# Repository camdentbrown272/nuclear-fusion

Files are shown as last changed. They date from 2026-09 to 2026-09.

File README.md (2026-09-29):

# nuclear-fusion — Cold-Fusion Geometry Optimisation

This repository documents a design effort to find the geometric configuration of a **cold** (condensed-matter, room-temperature-class) nuclear experiment with the best chance of producing a **measurable, credible** signal. All reasoning is written down so others can audit it.

## Start here
1. [`docs/00-charter.md`](docs/00-charter.md): mission, scope, honest prior, the two hypotheses.
2. [`docs/01-master-plan.md`](docs/01-master-plan.md): phases, candidate configurations, evaluation matrix.
3. [`docs/models/M0-rate-budget.md`](docs/models/M0-rate-budget.md): first-principles numbers that set the design objective.

## Layout
| Path | Contents |
|---|---|
| `docs/research/` | Literature digests R1–R7 with evidence grades |
| `docs/models/` | Quantitative models M0–M6 (briefs in `docs/models/briefs/`) |
| `docs/decisions/` | Architecture/decision records (ADR) |
| `docs/design/` | Iteration designs and red-team reviews |
| `sim/` | Model code (`python3 sim/<file>.py`; needs numpy, scipy, matplotlib) |

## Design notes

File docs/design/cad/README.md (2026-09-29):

# 3D model — iteration 1 rev C

Generated by `sim/cad_dfm.py` (CadQuery; `pip install cadquery`). Every dimension comes from
`docs/design/iteration-1.md`; change a parameter at the top of the script and rerun to regenerate.

| File | Use |
|---|---|
| `dfm_cell.step` | Single DFM cell, editable CAD (Fusion 360, FreeCAD, SolidWorks, Onshape). True 12 µm membrane, full hex catch grid |
| `dfm_cell.stl` | Same cell as one mesh, for quick viewing or 3D printing (in mm) |
| `dfm_cell.glb`, `dfm_house.glb`, `gamma_station.glb` | Coloured meshes for any glTF viewer (Windows 3D Viewer, Blender, gltf-viewer.donmccurdy.com) |
| `dfm_house.step` | 8-position array in its Cu / ³He / borated-HDPE house (simplified cells) |
| `gamma_station.step` | NaI well calorimeter with the mini permeation cell in its Pb / borated-HDPE / veto shield (ADR-006) |
| `*.gltf.json` | Same meshes as self-contained glTF JSON, used by the web viewer |
| `viewer.html` | Interactive viewer (section cut, part descriptions) |

Run the viewer locally with `cd docs/design/cad && python3 -m http.server`, then open
<http://localhost:8000/viewer.html>. It loads three.js from a CDN.

The layers that are thinner than 0.1 mm are drawn at true thickness, except the Au exit finish
(50 nm, drawn 20 µm). The viewer can thicken the membrane, Au finish and ΔE detector ×40.

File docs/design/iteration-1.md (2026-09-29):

# Iteration 1 (rev C) — Detector-Facing Membrane Array "DFM-8" and claim arms

**Status:** revision C, after all four red-team-1 reviews and M7:
- [ADR-005](../decisions/ADR-005-iteration1-revB.md): physics, statistics and claim fidelity;
- [ADR-006](../decisions/ADR-006-gamma-station-modulation.md): γ station and modulation;
- [ADR-007](../decisions/ADR-007-engineering-revC.md): engineering and safety.
**Date:** 2026-09-29
**Frozen analysis plan:** [preregistration-v1.md](preregistration-v1.md)
**Earlier version:** rev A (git `77887a6`) used quadrant skins on one membrane. The reviews showed that geometry cannot hold the claimed regimes (ADR-005 §1).
**Lead designer:** Claude. Every parameter cites its source in §14.

---

## 0. The configuration in one paragraph

- **The membrane.** A **12 µm annealed palladium membrane, 20 mm active diameter**, forms the wall between two chambers.
  - It is press-bonded to a corrugated **platinum** annulus. Platinum does not absorb hydrogen, so the membrane can swell freely while an all-metal seal holds it.
  - Both chambers hold D₂ at 0.5 bar, so the membrane carries no significant pressure load. A 0.3 mm molybdenum grid and a relief valve protect it if that balance is lost.
  - Deuterium that crosses the membrane is **pumped back into the cell** through a closed, helium-tight loop. This keeps the sealed cell's gas and heavy water in balance (ADR-007).
- **The entry face (top)** is the cathode of a small **sealed, all-metal, PTFE-lined electrolytic cell**: 1.0 M LiOD in low-tritium D₂O, with a Pt mesh anode 4 mm above. The cell loads the membrane to D/Pd ≥ 0.9.
- **The exit face (bottom)** gets **one of three finishes per membrane**. Each finish sets the loading state of the *whole* foil:
  - **H-L:** 50 nm Au cap. High loading, no through-flux. It behaves like SRI's closed cathode, with deuterium movement driven by current steps.
  - **H-M:** 20 nm Ni. High loading with a small through-flux.
  - **FX:** half bare Pd, half Pd/CaO multilayer. Maximal flux at moderate loading.
- **Charged-particle detection.** A **quadrant silicon ΔE–E telescope** sits 4 mm below the exit face. Because the foil is thinner than the range of a 3 MeV proton, the telescope sees fusion protons from **anywhere in the foil**, including the electrolyte-facing surface. The proton energy tells roughly how deep they were born.
- **Helium-4.** Every cell accumulates ⁴He statically in two sealed, polymer-free volumes: the ~30 cm³ front and the headspace. Post-run melts recover retained helium.
- **The array.** **Eight such membranes from two screened Pd lots** run in two stages of four. Each stage shares a low-background house with four controls:
  - a Pt-membrane D₂O twin;
  - two light-water twins;
  - a blank telescope.
  - The house also contains a ³He neutron bank and a muon veto. The 511 keV / e⁺e⁻ channel runs in a separate lead-shielded **γ station** (ADR-006).
- **Parallel Tier-1 arms.** Two further arms run alongside and test the best-graded claims at their original conditions:
  - Iwamura-type gas-permeation transmutation cells (**C3-G**, Cs→Pr);
  - four SRI-type closed wire cathodes (**C1**).

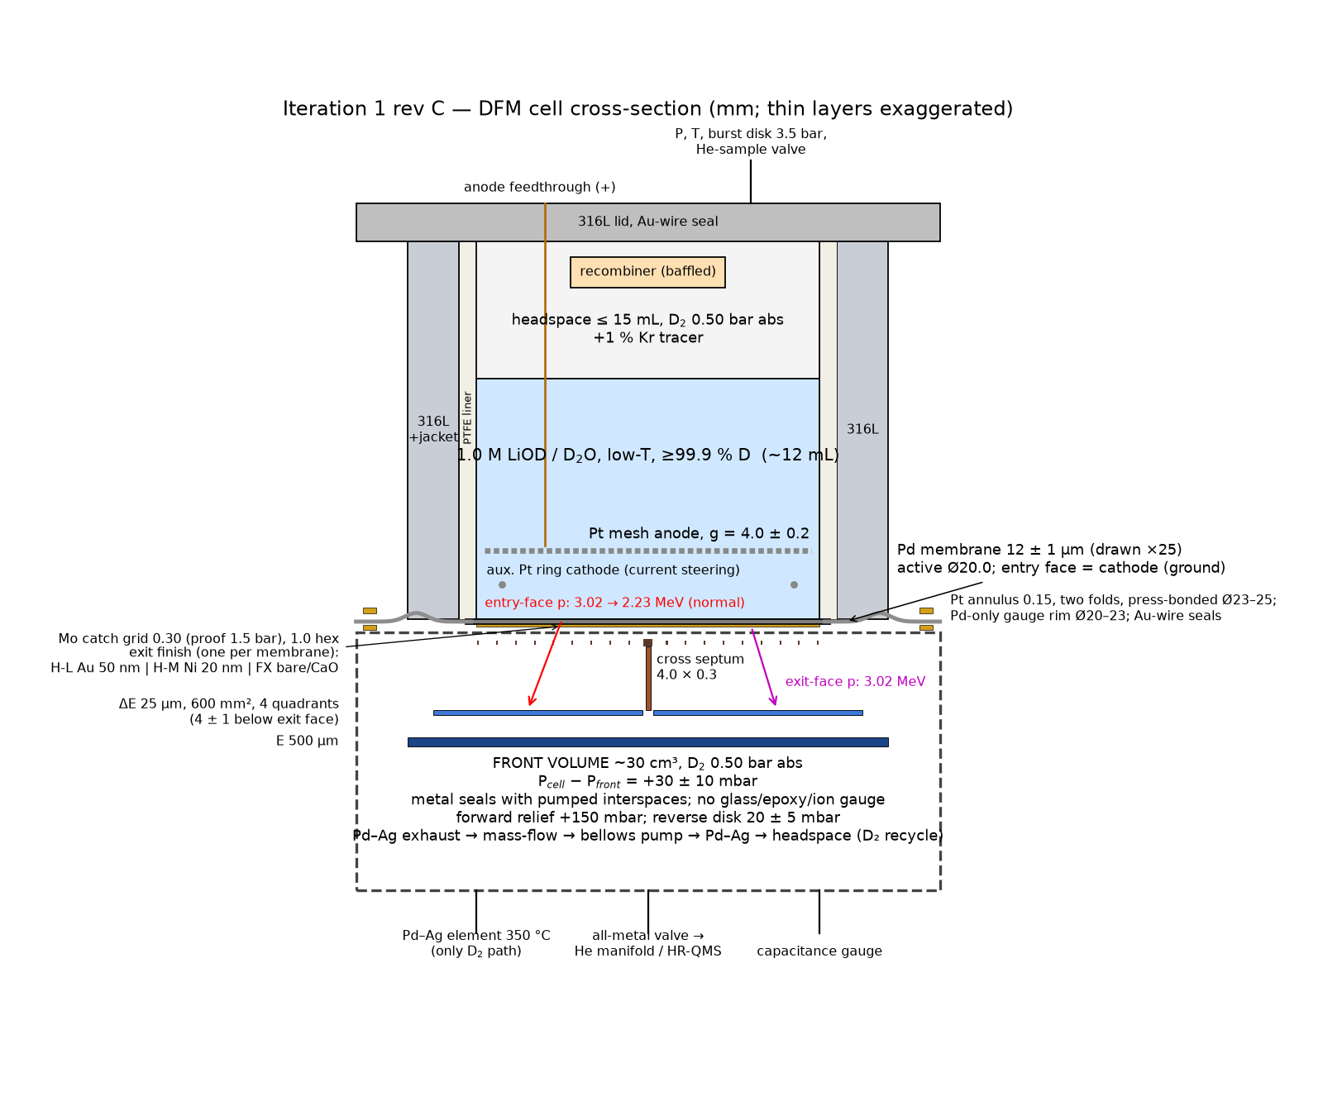
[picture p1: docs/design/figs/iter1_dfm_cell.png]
DFM cell cross-section


**3D model:** STEP/STL/glTF files and an interactive viewer are in [`cad/`](cad/README.md) (generated by `sim/cad_dfm.py`).

## 1. Objective and honest odds

- **Objective (ADR-003).** Reproduce the claimed conditions at a detector-visible location, in enough independent samples, with detectors reaching ≲ 1 % of each claimed magnitude, and with controls that make a detection credible.
- **Physics prior (M0).** The gap to a detectable rate under standard physics is 89–115 e-folds. Static screening gives about 9–13 eV at every lattice site (M1).
- **P(claim-rule positive).** P(any claim-rule positive that survives controls) ≲ 3 %.
- **What a null buys.** An all-null outcome sets **magnitude limits conditional on reaching the claimed regime**, per claim, normalised per area and per volume. Its Bayes factor against existence is only ~1.4–1.6 (red-team-1C S-7). It is *not* a refutation, and the write-up will say so (pre-registration §5).

## 2. Programme architecture

| Tier | Arm | What it tests | ADR-003 score (1D §4, revised) |
|---|---|---|---|
| **1** | **DFM-8** (§3–§6) | H1a (charged particles at every depth), H2 (⁴He, the most sensitive accounting), SRI loading at a visible location, flux regime, desorption | ≈ 0.53 for SRI plus Lipson/NTT terms; the only arm that makes H1 nulls informative |
| **1** | **γ station** (§4.3, ADR-006) | H1c: Czerski e⁺e⁻ channel. 8″×8″ NaI well around a mini permeation cell, D₂O/H₂O factorial | ≈ 0.14–0.2; MDA 5×10⁻³ pairs s⁻¹ at sea level, 3×10⁻⁴ at ≥ 30 m w.e. |
| **1** | **C3-G ×5** (§7.1) | Iwamura permeation transmutation, primary Cs→Pr | ≈ 1.1 |
| **1** | **C1 ×4 + H₂O twin** (§7.2) | SRI/ENEA heat + ⁴He in closed wire cathodes | ≈ 0.7 |
| 2 | Nanocomposite / Ni–Cu furnace (§8.2) | Kitamura / Clean Planet | promoted when claimant-lineage material is secured |
| 3 | Co-deposition on a PSD scintillator (§8.1) | SPAWAR chemistry | low credibility, cheap |

## 3. The DFM cell

### 3.1 Cross-section

Dimensions in mm unless noted; not to scale.

```
                 anode feedthrough (alumina-brazed, +)      P, T, burst disk (3.5 bar), He-sample valve
                          |                                        |
        +=================|========================================|=============+  316L lid, Au-wire seal
        |  headspace <=15 mL, D2 0.50 bar abs (+1 % Kr); make-up/recycle inlet  |
        |  recombiner (hydrophobic Pt/Al2O3, >=20 above liquid, baffle, arrestor) |
        |  +-- 316L body (water jacket), PTFE liner 1.0 spring-loaded, bore 20 -+ |
        |  |  1.0 M LiOD / D2O (low-T, >=99.9 % D), ~12 mL                        | |
        |  |  ======== Pt mesh anode (>=50 % open, pitch <=1) ========  g = 4.0   | |
        |  |  o aux. Pt ring cathode (current steering, ADR-006)   RTD thermowell | |
        |  |  ~~~~~~~~ ENTRY FACE = cathode (ground), etched annealed Pd ~~~~~~~~ | |
        +--+=====================================================================+-+
           |  Pd MEMBRANE 12 +/- 1 um, active dia 20.0, Pd-only rim to dia 23   |    4-pt vdP on Pd-only rim (dia 22)
           |  press-bonded (850 C, 5-10 MPa, Pt interlayer) dia 23-25 to         |<-- Au-wire seals both sides
           |  Pt annulus 0.15, ID 23 / OD 36, two convolutions                   |
           |  EXIT FACE: one finish per membrane (Au 50 nm | Ni 20 nm | F/X)     |
        +--o---------------------------------------------------------------------o--+
        |  Mo catch grid 0.30 (stress-relieved), 1.0 hex holes, 0.15 webs, proof 1.5 bar |
        |  cross septum 4.0 x 0.3 (grounded) = deep rib under the grid (10 mm spans)  |
        |  [dE 25 um, 600 mm2, 4 quadrants]  4.0 +/- 1.0 below exit face            |
        |  [E 500 um, >=700 mm2]             1.5 below dE                           |
        |  FRONT VOLUME ~30 cm3, D2 0.50 bar abs; dp(cell-front) = +30 +/- 10 mbar  |
        |  vacuum-fired 316L(N); metal seals with pumped interspaces; no glass/epoxy/ion gauge
        |  forward relief cell->front at +150 mbar; reverse disk 20 +/- 5 mbar front->cell |
        +-----+-----------------------+----------------+-----------------------------+
              |                       |                |
     Pd-Ag element (350 C)     all-metal valve to   capacitance gauge
     = only D2 in/out path     He manifold/HR-QMS
        |
     mass-flow meter (flux regressor) -> bellows pump -> buffer -> Pd-Ag -> cell headspace
     (closed D2 recycle loop on FX/H-M cells; Pd-Ag-purified make-up supply for P1 and H-L)
```

### 3.2 Dimensions and materials

| Item | Specification | Source |
|---|---|---|
| Membrane | Pd ≥ 99.95 %, **12 ± 1 µm** unloaded, measured per foil to ± 0.3 µm; Ø20.0 wetted/active | ADR-005 §2.2; M2 rec. 6 |
| Lots | ≥ 2 lots, screened on sibling coupons before admission: loading ≥ 0.95 in D₂O at ≤ 300 mA cm⁻²; swelling; EBSD texture and grain/thickness ratio; ICP-MS impurities. ENEA/SRI archival material requested | ADR-005 §2.4; 1D-D3 |
| Heat treatment and bond | Vacuum anneal 850 °C, 1 h, ≤ 10⁻⁵ mbar, done together with a **press bond** (ceramic platens, 5–10 MPa, sputtered Pt interlayer) over Ø23–25; entry face lightly etched afterwards. Bond qualified first on ≥ 10 coupons: He leak ≤ 10⁻¹¹ mbar L s⁻¹ before and after 3 load/deload cycles, peel test, cross-section | ADR-007 §2.4 (1B-B7) |
| Membrane blank and rim | Ø25 blank; Pd-only rim Ø20–23 carries the van der Pauw contacts, so they are not shunted by the Pt | ADR-007 §2.4 (1B-B6) |
| Annulus | Pt, **0.15 mm, ID 23 / OD 36, two convolutions**, ≥ 1 mm radial travel (the loaded disk grows ≈ 0.45 mm in radius) | ADR-007 §2.4 (1B-B15) |
| Seals | Au-wire on both sides of the annulus. No elastomer or polymer on any gas boundary | 1A-P1; M8 |
| Cell body | 316L with a **water jacket**. PTFE liner 1.0 mm on all wetted surfaces (no path to air), spring-loaded onto the foil by an Au-plated wave spring, baked 150 °C, D₂-purged. Headspace ≤ 15 mL. Liquid-level pins; electrolyte RTD in a PTFE thermowell | 1A-P1; R6; ADR-007 §2.5 |
| Anode | Planar Pt mesh (≥ 50 % open, pitch ≤ 1 mm), g = 4.0 ± 0.2 mm, parallel within 0.2 mm | M2 rec. 7 |
| Auxiliary cathode | Pt ring (Ø0.5 mm wire, Ø17 mm) 2 mm above the membrane, outside the active face's shadow. Takes the steered current during lock-in "off" half-periods (ADR-006) | ADR-006 §3 |
| Electrolyte | 1.0 M LiOD in D₂O, ~12 mL. D₂O ≥ 99.9 % D, certified low-tritium, LSC assay per lot. ²²⁸Th/²²⁶Ra assay of LiOD. Rn-free by sparging with Pd–Ag-purified D₂ | M2; 1A-P8, P9; 1D-D15 |
| Cell gas and D balance | D₂ 0.50 ± 0.05 bar abs, held by a pressure controller. **Closed D₂ recycle loop** on FX/H-M cells: front Pd–Ag exhaust → mass-flow meter → metal-bellows pump → buffer → second Pd–Ag → headspace. Pd–Ag-purified make-up for P1 and H-L cells. Two-sided trip at ± 10 % of fill; O₂ inferred from the D balance and measured by QMS sniff every 6 h | ADR-007 §2.1 (1B-B1) |
| Recombiner | Hydrophobic Pt/Al₂O₃, ≥ 20 mm above the liquid, baffle, flame arrestor, thermocouple | R6 |
| Exit finishes | H-L: Au 50 nm (pinholes ≤ 3×10⁴ cm⁻², checked per sputter batch by an H-permeation witness and Cu decoration). H-M: Ni 20 nm (final value from P0b). FX: diagonal quadrant pairs F (bare) and X (Pd 40 nm / [CaO 2 nm / Pd 18 nm]×5), separated by a 1 mm bare web | ADR-005 §2.1; 1A-P7 |
| Grid | Photo-etched, stress-relieved Mo **0.30 mm**, 1.0 mm hex holes, 0.15 mm webs (open 0.76), carried by the 4 mm cross septum as a deep rib (10 mm spans). ≈ 160 MPa at 1.0 bar against a yield of 550–700 MPa. Proof-tested at 1.5 bar. Proton transmission over the acceptance 0.43 | ADR-007 §2.2 (1B-B3) |
| Pressure | ΔP = P_cell − P_front: operate +30 ± 10 mbar, alarm ± 15, trip at +5 / +60 mbar, with temperature feed-forward. Trip action: galvanostat to 0 (FX/H-M) or keep-alive (H-L); Pd–Ag heaters stay on. Forward relief cell → front at +150 mbar. Reverse-acting, vacuum-supported disk front → headspace at 20 ± 5 mbar (lifted membrane at 50 mbar ≈ 54 MPa). Burst disks (3.5 bar) on cell and front to a vent volume. The full hierarchy is in ADR-007 §2.2 | ADR-007 §2.1–2.2 (1B-B2, B5, B17) |
| Telescope | ΔE 25 ± 2 µm, 600 mm², 4 quadrants; E 500 µm; ΔE at 4 ± 1 mm; ceramic, epoxy-free, low-α; bias ≤ 150 V, current-limited to ≤ 1 µA with µs trip, interlocked off between 0.05 and 50 mbar and during ramps > 5 mbar s⁻¹. ΔE–E gap vented. Mounts thermostatted. ≥ 2 spares; one sacrificial telescope soaked in D₂ from P0a. Fallback: vacuum pocket behind a 1–2 µm SiNₓ or Ni window | M5 rec. 1; ADR-007 §2.6 |
| Septum | Cross, 4.0 × 0.3 mm, grounded. Its (n,xp) contribution (~0.01 d⁻¹) is included in the background; B carries an identical septum and grid on one quadrant | 1A-P11 |
| Front volume | ~30 cm³, vacuum-fired 316L(N). Every demountable seal has a pumped or Ar-guarded interspace. D₂ only through the hot Pd–23Ag element. Three-valve pumped-interspace isolation to the manifold | M8; ADR-007 §2.7 |
| Loading gauge | 4-point van der Pauw on the Pd-only rim at Ø22, valid because each membrane is single-regime. R(x) calibrated on **bonded** sibling assemblies for D and H, both branches. Rim thermostatted to ± 0.05 K. Logged at ≥ 1 Hz | ADR-005 §2.4; ADR-007 §2.4 |
| Other sensors | ≥ 2 acoustic-emission sensors per cell (to localise events); flange RTD; cell and front pressure; Δp transducer | 1A-P3 |
| Electrical | Membrane is the hard ground; floating linear galvanostat; dummy Si on the same electronics; waveforms digitised at ≥ 100 MS/s; V·I at ≥ 100 kS/s | red-team-0 §3.4; M4 |

### 3.3 Membrane types and allocation

| Type | Exit finish | Whole-foil state (M2/M3) | Primary role | Claim terms |
|---|---|---|---|---|
| **H-L** | Au 50 nm | x ≈ x_in = 0.915–0.924 (good surface), J ≈ 0; \|dx/dt\| from cathodic steps | SRI/ENEA loading at a detector-visible location; the exit face is also in-regime (visible at 3.0 MeV, ε = 0.22) | SRI/ENEA, NTT-like (P6a) |
| **H-M** | Ni 20 nm | x ≈ 0.91–0.92, J ~ 10 mA cm⁻² | McKubre's (x − x₀)²·flux product. **Pre-registered fallback: built as H-L if P0b shows no loaded-flux window** | SRI flux term |
| **FX** | F / X diagonal pairs | x ≈ 0.65 throughout, J supply-limited (50–150 mA cm⁻² equivalent) | Flux-regime H1, F vs X within one membrane, lock-in, desorption | Lipson-like (P6a), Czerski, generic interface |

**Allocation.** Two stages of four active cells; lots a and b; positions rotated between stages.

| Stage | A1 | A2 | A3 | A4 |
|---|---|---|---|---|
| 1 | H-L (a) | H-L (b) | H-M (a) | FX (b) |
| 2 | FX (a) | H-M (b) | H-L (a) + **Al additive** | H-L (b) |

- **Totals:** H-L 4, H-M 2, FX 2.
- **Controls in both stages:** T-Pt, T-H(L) and T-H(FX), plus B.
- **Stage-2 freeze:** the stage-2 allocation is frozen as pre-registration amendment A1 before stage 1 is unblinded.
- **Replication odds.** With 8 membranes, P(≥ 2 active) = 0.50 at p = 0.2 and 0.19 at p = 0.1 (1C §C.4). Lot correlation lowers both.

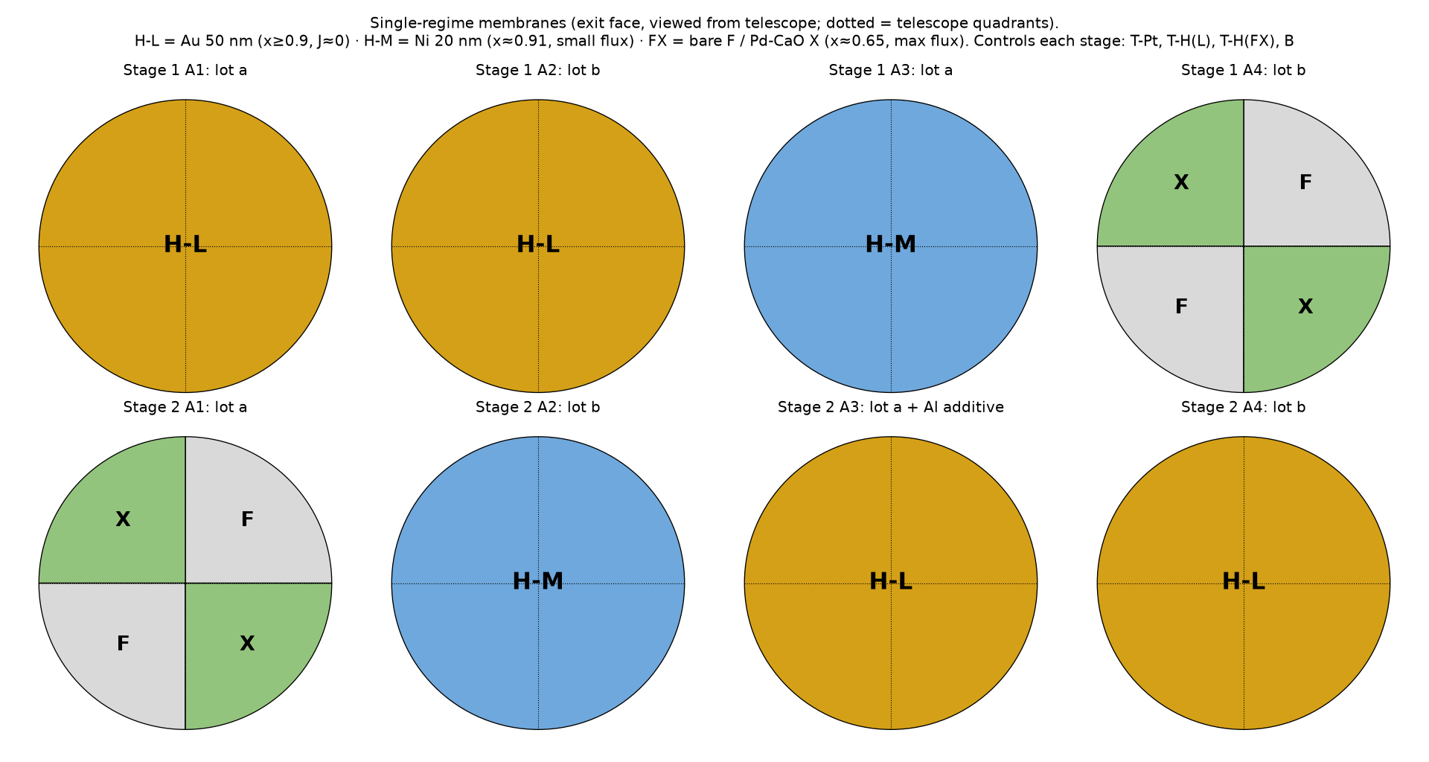
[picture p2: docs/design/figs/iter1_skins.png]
Membrane types and allocation


Drawings are generated by `sim/design_iter1_drawing.py`.

### 3.4 What the telescope sees

Proton energies at the ΔE, through 12.46 µm (loaded) PdD₀.₉ plus 4 mm of 0.5 bar D₂, over the real acceptance (`m5_si_telescope`):

| Proton origin | Normal incidence | Acceptance median, 10–90 % | ε_PID (δ source) |
|---|---|---|---|
| Exit face | 3.02 MeV | 3.01 [3.01, 3.02] | 0.220 |
| 4 µm | 2.78 | 2.66 [2.33, 2.76] | 0.214 |
| Mid-foil | 2.64 | 2.45 [1.90, 2.61] | 0.209 |
| **Entry face** | 2.23 | 1.80 [0.00, 2.17] | **0.162** |

- **Energy is not a one-to-one depth map.** Depth is recovered by a pre-registered response-matrix unfold ε(z, E), calibrated with ⁶LiF tritons (34 % emerge at 12 µm). One ⁶LiF calibration membrane is made per lot.
- **Tritons** escape from the top ~4 µm, **³He** from ≤ 1 µm.
- **Radon progeny.** ²¹⁴Po α leave the foil at ≤ 2.8 MeV and stop in the ΔE, so PID rejects them.
- **Grid and septum** multiply efficiency by ≈ 0.43 × 0.9. The 0.30 mm grid's hole walls shadow oblique tracks (transmission over the acceptance: 0.43, against 0.70 for a 0.10 mm grid; ADR-007 §2.2).

## 4. Array and house

### 4.1 Positions (per stage)

| Position | Cell | Role |
|---|---|---|
| A1–A4 | DFM, D₂O, per §3.3 | Active |
| T-Pt | DFM geometry with a Pt membrane (flux-blocked), identical D₂O volume and current waveform | **Primary T1 control**: D₂O cosmic recoils (n–d, D(n,np)), EMI/current artifacts, cell→front leaks; neutron control |
| T-H(L) | H₂O/LiOH, H-L type | Isotope-specificity check. Two blocks: current-matched and x-matched, under a deterministic controller frozen after P0b |
| T-H(FX) | H₂O/LiOH, FX type | Isotope-specificity check (current-matched and J-matched blocks) |
| B | Blank telescope under 100 µm Al; one quadrant carries septum and grid | Internal, cosmic and EMI background |

Telescopes are characterised in P0a and P6 (≥ 10× live time each). There is no mid-run swap, because swapping would break the He windows (1C-S12).

### 4.2 House (plan view)

```
 +----------------------------------------------------------------------+  20 cm borated HDPE + 1 mm Cd
 |  3He bank: 24 x 1" x 40 cm tubes (4 atm) in HDPE, lining 4 walls     |
 |   +------------------------------------------------------------+     |
 |   |  5 cm OFHC Cu inner shield (no Pb near the bank)            |     |
 |   |    [A1]   [A2]   [A3]   [A4]         <- 90 mm pitch         |     |
 |   |    [T-Pt] [T-H(L)] [T-H(FX)] [B]                             |     |
 |   +------------------------------------------------------------+     |
 |  plastic-scintillator muon veto on top and two sides                 |
 |  chilled-water loop inside the Cu (removes ~230 W of cell heat)      |
 +----------------------------------------------------------------------+
 Inner cavity ~ 45 x 30 x 30 cm; 3He-bank efficiency ~0.12-0.18 (M5 scaling)
 D2 supply to the house: excess-flow valve and restrictor outside, H2 sensor inside
```

The house has **no γ detectors and no lead** (M5: Pb near the ³He bank fakes neutrons). The Si telescopes record the MIPs from any e⁺e⁻ pairs, and ΔE–E classification keeps them out of the proton window (M7).

### 4.3 γ station (ADR-006)

```
   +--------------------- 5 cm plastic veto (5 faces, 20 us window) ---------------------+
   | +------------------------- 10 cm Pb (15 cm if >= 30 m w.e.) ----------------------+ |
   | | +------------------ 5 cm borated HDPE (5 % B), N2 purge -----------------------+ | |
   | | |          8" x 8" NaI(Tl) well calorimeter (68 % eff. 12-30 MeV)            | | |
   | | |              [ mini permeation cell in the well ]                           | | |
   | | |              12 um Pd FX-type, exit face on UHV + RGA (flux regressor)     | | |
   | | |              aux. Pt cathode for current steering                           | | |
   | | +----------------------------------------------------------------------------+ | |
   | +--------------------------------------------------------------------------------+ |
   +--------------------------------------------------------------------------------------+
   >= 2 m from the 3He house. Two identical mini cells (D2O, H2O) alternate in 5-day blocks.
```

- **Channels:** summed deposit in 12–30 MeV (above all thermal-capture lines); 511 coincidences between well segments; MIP tag.
- **MDA** in 30 d: 5×10⁻³ pairs s⁻¹ at sea level; 3×10⁻⁴ at ≥ 30 m w.e. (M7).
- **Blank:** 14 d with an Au foil at the same current before physics (hadronic normalisation, ×3 uncertainty).
- **Calibration:** exempt ²²Na (0.1 µCi); cosmic muons and Michel electrons.

## 5. Helium system

- **Two channels per cell:**
  - **Front** (exit-face reactions). Release fraction by finish (M8, 1A-P12): F ≈ 0.85; H-M (20 nm Ni) ≈ 0.6; X 0.02–1; H-L ≈ 0 (the Au cap retains He, so melts are needed).
  - **Headspace** (entry-face reactions). Release into the front is 0. On FX and H-M cells the D₂ recycle loop feeds this volume, so the headspace channel is **descriptive unless P0a blanks taken with the loop running meet ≤ 3× the target floor** (ADR-007 §2.1).
- **Manifold** (0.1–0.2 L, 250 °C bakeable):
  - getter;
  - **HR-QMS (R ≥ 500)**;
  - ⁴He and ³He pipettes;
  - capacitance gauge;
  - ports for external magnetic-sector MS with ³He isotope dilution. The ³He spike is ≥ 100× the tritium ³He ingrowth. The sector MS is used on a pre-registered subset of ≤ 60 samples; HR-QMS is primary.
  - three-valve pumped-interspace isolation to each cell.
- **Windows.** 1 d and 7 d static windows. During P2 the FX membranes permeate 50–150 mA cm⁻² equivalent, so windows rely on the Pd–Ag exhaust, not on getter capacity (1A-P10).
- **Floors (5σ, full release, M8):** 0.39 nW (1 d) and 0.16 nW (7–30 d), i.e. 43–100 He s⁻¹. These are **targets to be earned in P0a**. They need a polymer-free cell (1A-P1) and total seal leakage ≤ 3×10⁻¹⁴ mbar L s⁻¹, which is why every seal has a pumped interspace (1B-B9).
  - Each cell's floor is measured in P0a, with blanks taken **after** filling and a ≥ 30 min sparge.
  - Acceptance: a floor ≤ 3× target, otherwise that cell's He is descriptive.
  - The **10× floor is the pre-registered planning case**; its reach is still ~10⁻⁷ of the claims.
- **T3 statistic.** Each cell's excess over its **own** blank series, with the between-cell variance and D₂-matrix spikes included (pre-registration §2).
- **Post-run.**
  - Quadrant melts (laser-cut).
  - Sibling-coupon melts per lot.
  - ³He implanted off-site into a sibling membrane, to measure release fractions (sample preparation only, not a device beam).
- **Hygiene.**
  - Vent only with LN₂ boil-off N₂.
  - Use Ar/Kr for leak checks, never He after the final bake.
  - No He cylinders in the room; log room He.
  - Weekly H/D in headspace aliquots.

## 6. Calorimetry

- **Instrumented cells.** One H-L cell per stage and T-H(L) sit in SEEB1\* Seebeck envelopes, with a ≥ 10 mm Cu shell and a ceramic break to the front (5σ ≈ 4–20 mW, M4).
- **Power metrology.** V·I is sampled at ≥ 100 kS/s. Permeation and loading enthalpies are pre-registered.
- **Status.** Heat is **partially tested**: 4–20 mW, volume-scaled, is 2–100 % of SRI-scale claims (1C-S6). It is descriptive only.

## 7. Tier-1 claim arms

### 7.1 C3-G ×5: Iwamura gas-permeation transmutation

- **Substrate.** Pd 25 × 25 × 0.1 mm, prepared by the MHI recipe (anneal, etch).
- **Entry face.** Pd 40 nm / [CaO 2 nm / Pd 18 nm]×5, then **Cs** as the primary target: ¹³³Cs → ¹⁴¹Pr, the Toyota-replicated channel. Both isotopes are monoisotopic, and the Pr background is surveyed pre-run. ⁸⁶Sr is a secondary target on separate cells (⁸⁶Sr → ⁹⁴Mo). Targets are applied off-site as sample preparation.
- **Conditions.** D₂ 1 atm upstream, 70 °C, vacuum downstream with an RGA logging J (target 3–7×10¹⁷ D cm⁻² s⁻¹), 2 weeks per sample.
- **Cells.** 3 D₂ (Cs), 1 H₂ (Cs), 1 no-CaO (Cs). **No Mo anywhere in C3-G.** Zr survey (⁹⁴Zr isobar).
- **Analysis.** Coded samples; blinded pre/post ICP-MS and ToF-SIMS at two labs. Reach is quoted as isotope-ratio precision. Separately registered (T4).

### 7.2 C1 ×4 + H₂O twin: SRI/ENEA closed cathodes

- **Cathode and anode.** Pd wire Ø1.00 × 30 mm between PTFE end plates, Pt helix at R = 10 mm (M2 §6.1).
- **Electrolyte.** **1.0 M LiOD** (SRI lineage), 60 mL, in an all-metal 316L cell.
- **Lots and variants.** 2 screened lots (2 cells each). Variants, each descriptive: one cell with **Al additive** (LiAlO₂, ~200 ppm); one cell with a **SuperWave-type** waveform.
- **Protocol.** ≥ 6 weeks at x ≥ 0.9; cathodic current steps; excursions to 0.5 A cm⁻².
- **Channels.**
  - SEEB1\* twin calorimetry (M4).
  - Headspace ⁴He on the shared manifold; post-run melts.
  - An 8-tube ³He bank around the bath.
  - CR-39 channel C against the wire (M5 rec. 9).

## 8. Tier-2/3 arms (outline)

- **8.1 Co-deposition** on EJ-276 PSD plastic under 50 nm Au. PdCl₂ + LiCl in D₂O, open vented cell, with an H₂O twin. Descriptive.
- **8.2 Nanocomposite furnace.**
  - 100 g CNZ/PNZ at 200–300 °C in an all-metal reactor, with a flow calorimeter (± 0.1–0.2 %) and an inert-bed twin, plus ⁴He/³He on the shared manifold.
  - Ni/Cu multilayer variant: 6×[Cu 2 / Ni 14 nm] on Ni, H₂-loaded at 250 °C, then desorbed with a ramp to 900 °C.
  - Promoted to Tier 1 once claimant-lineage material is secured.

## 9. Protocol (per stage)

The full inference rules are in [preregistration-v1.md](preregistration-v1.md).

| Phase | Duration | Action | Notes |
|---|---|---|---|
| Development (before stage 1) | 6–10 months | Bond qualification (≥ 10 coupons); grid proof tests; Si D₂-soak telescope started; **P0b on a separate bench**: bare-Pd and H-L witness DFMs at 0.5 bar D₂ measure J(i), x, the Au pinhole leak, τ_eff, V_cell and ΔT at 0.5 A cm⁻². P0b chooses the Ni thickness for H-M or triggers the H-M → H-L fallback | ADR-007 §2.8 (1B-B7, B13); 1A-P7 |
| P0a Commissioning | 3–4 wk (stage 1), 2 wk (stage 2) | ²⁴¹Am + pulser, ²²Na, ⁴He/³He spikes; per-cell He blanks after fill (≥ 3 × 1 d, ≥ 2 × 7 d, with the recycle loop running on FX/H-M cells); calorimeter calibration; backgrounds ≥ 10× live time | Freeze DQ cuts, controller targets and He acceptance |
| P1 Loading | 1 d | α→β transit at 5 mA cm⁻², then 20 → 50 → 100 → 300 mA cm⁻². ΔP held ≤ +10 mbar during the transit. Headspace D₂ topped up from the purified make-up supply (loading consumes 69 % of it) | M3 Protocol A; ADR-007 §2.1–2.2 |
| **P2 Hold** | **42 d fixed** | 200–300 mA cm⁻², electrolyte 22 ± 1 °C (RTD), keep-alive ≥ 20 mA cm⁻² on UPS. FX: ≥ 25 % current-off blocks. D₂ recycle loop on FX/H-M. He windows | Primary T1/T3 data; in-regime hours logged |
| P3 Modulation | 14 d | Lock-in at P = 12 τ_eff (from P0b), clipped to 1–6 h (default 2 h), randomised blocks, **current steered to an auxiliary Pt cathode** so cell heat and field stay constant (ADR-006). H cells: cathodic 100 ↔ 500 mA cm⁻² (≤ 2 h at 500). FX: steering on/off, plus balanced front-and-cell pressure ramps 0.2 ↔ 0.6 bar at ≤ 1 mbar s⁻¹ and constant current. Anodic excursions are capped at ≤ 10 % of the foil inventory per half-cycle (−10 mA cm⁻², or −100 mA cm⁻² for ≤ 8 s) and are descriptive only | Regressor: FX exit flux (mass-flow meter on the Pd–Ag exhaust); H cells \|dx/dt\| (vdP) |
| P4 Warm | 14 d | Fill 0.5 bar, electrolyte 55 °C, ramp ≤ 5 K h⁻¹; trip re-zeroed at temperature; Si ≤ 30 °C | 1D-D12; ADR-007 §2.5 |
| P6a Desorption | 2 d | Current off. Cell lowered to ≤ 50 mbar **before** the front is pumped through the HR-QMS line. Telescopes on (bias interlocked through 0.05–50 mbar). Dynamic He logged | Lipson/NTT-like; 1D-D13; ADR-007 §2.2 |
| P6 End | 1 wk | Final He windows (before P6a); section and melt; SIMS/ICP-MS; XPS for Pt on the entry face; AFM/EBSD | Ash and covariates |

**Descoped from rev A:** α/β cycling site factory (P5). Misfit cracking is a confound, so it is moved to iteration 2.

## 10. Sensitivity versus claims

Per claim, normalised as stated; live time 0.8; P2 42 d.

| Channel / claim | Reach | Claimed magnitude | Ratio | Status |
|---|---|---|---|---|
| Si T1, pooled 8 membranes (per membrane) | 2.0–4.2×10⁻⁵ fusions s⁻¹ (`design_iter1_reach.py`, background 0.03–0.09 d⁻¹, 0.30 mm grid) | Lipson 4×10⁻³ p s⁻¹ (4π, M5) | ~0.3–0.5 % | tested |
| Si, single membrane | 0.9–1.5×10⁻⁴ | same | ~1–2 % | tested (descriptive) |
| Si vs the Tohoku-static prediction (M1) | ~2 events/day threshold | ~130/day | ~1.7 % | partially tested |
| ⁴He front (F/H-M) | 0.16–0.39 nW target; 1.6–3.9 nW planning case | SRI 0.1–1 W, volume-scaled to 3.1 cm² × 12 µm: ~15–150 mW | ~10⁻⁸ | tested |
| ⁴He headspace + melts | ~0.4–1.6 nW-equivalent | same | ~10⁻⁸ | tested |
| Heat (H-L, T-H(L); C1) | 4–20 mW; 7–27 mW | volume-scaled SRI | 2–100 % | partially tested |
| γ station, e⁺e⁻ (T2) | 5×10⁻³ pairs s⁻¹ (sea level); 3×10⁻⁴ (≥ 30 m w.e.) | not quantified by the claimant | — | tested (existence) |
| Neutrons | ~2×10⁻² fusions s⁻¹ | — | — | descriptive |
| C3-G Pr (T4) | isotope-ratio precision ~1 % on ~10¹⁰ cm⁻² | Toyota Pr 2×10¹¹ → 1.6×10¹² cm⁻² | ≲ 10⁻¹ | tested |

## 11. Safety envelope (R6 constraints → design)

| Constraint | Implementation |
|---|---|
| Headspace ≤ 50 mL | ≤ 15 mL per DFM cell |
| O₂ control | A permeating cathode turns pressure **loss** into the hazard signal (1B-B1). D₂ recycle loop and make-up; two-sided trip at ± 10 % of fill; O₂ inferred from the D balance and sniffed by QMS every 6 h; liquid level; recombiner thermocouple |
| Recombiner placement | ≥ 20 mm above liquid, baffle, flame arrestor |
| O₂-clean parts | PTFE, Pt, Pd, 316L, Mo, Cu, Au, alumina; no oils |
| Stored D | membrane 3.8×10⁻³ cm³ (≈ 0.06 kJ) |
| SELV | 3.1–5.2 V at 300 mA cm⁻² and 4.1–7.3 V at 500 mA cm⁻², depending on bubble void fraction (1B §3); ≤ 60 V holds |
| Thermal | Water-jacketed cells; chilled loop in the house; hardware over-temperature trip at +5 K |
| Trips (hardwired, on UPS) | ΔP trip at +5 / +60 mbar → galvanostat to 0 (FX/H-M) or keep-alive (H-L), Pd–Ag heaters stay on; low/high cell pressure; temperature; level; room H₂ 1 %; neutron bank at 10× background; m/z 20 or rupture signature → isolate and cool the Pd–Ag element, Si bias off (HV current-limited ≤ 1 µA) |
| Pressure hierarchy | Grid rated to 1.0 bar forward (proof 1.5 bar); forward relief cell → front at +150 mbar; reverse disk 20 ± 5 mbar; burst disks 3.5 bar on cell and front to a vent volume (ADR-007 §2.2) |
| UPS scope | galvanostats, Pd–Ag heaters, pressure controllers, PLC, gauges, chiller control; remote paging |
| Radiation | exempt check sources only; licensed neutron sources only at a partner facility |

## 12. Budget

These are estimates; vendor quotes are required. Rev C re-baselines the budget after red-team-1B (B12) found the rev B figures under-priced by about 2×.

| Block | Tier 1 (excluding labour) |
|---|---|
| Pd (≥ 2 lots, coupons, witnesses, calibration membranes), Pt annuli, bond development ($15–25k), finishes, grids, septa | $50–70k |
| Si telescopes: custom epoxy-free quadrant ΔE + E, NRE, 2 spares, soak unit | $110–160k |
| Digitisers and low-noise preamps (≈ 60 channels), HV | $80–120k |
| All-metal lined, jacketed DFM cells and fronts ×8 | $50–70k |
| Gas and He system: ≈ 60 all-metal valves, 24 capacitance/Δp gauges, 9 Pd–Ag elements, NEGs, pumps, pumped interspaces | $170–300k |
| D₂ recycle and make-up loops (per FX/H-M cell) | $25–50k |
| HR-QMS | $55k |
| External analyses (sector-MS subset ≤ 60 samples, SIMS, EBSD/ICP-MS screening, LSC) | $60–100k |
| ³He neutron bank (24 tubes) and electronics | $100–200k |
| Muon veto, chillers, jackets, house cooling | $40–60k |
| Galvanostats ×8, UPS (extended scope) | $20–30k |
| Seebeck calorimetry (DFM) | $15k |
| Consumables | $10k |
| **DFM-8 subtotal** | **≈ $0.8–1.3M** |
| γ station (NaI well + PMT, ~1 t Pb, veto, 2 mini cells, RGA) | $60–90k |
| C3-G ×5 (cells, multilayers, off-site targets, two-lab analyses) | $80k |
| C1 ×4 + twin (cells, SEEB1\*, 8-tube bank) | $70k |
| **Tier 1 total** | **≈ $1.0–1.5M**, plus 3–4 FTE for ≈ 1.5 years |
| **Minimum claim-weighted subset**: C3-G ×5 + C1 ×2 + twin + one DFM stage (2 H-L + T-Pt + T-H(L) + B, external He analysis) | **≈ $0.45–0.6M** |

**Schedule:** 15–20 months to the end of stage 2. That is 6–10 months of procurement and development (custom Si 16–26 weeks, bond qualification 6–8 weeks, He-system commissioning) followed by two ≈ 16-week stages.

## 13. Go / no-go for iteration 2

| Outcome | Iteration 2 |
|---|---|
| Claim-rule positive on T1 or T3 | Blind replication at an independent site with the same drawings; a ≥ 3-level J/x ladder; an unloaded-Pd dummy in the same cell; DSSD localisation |
| Evidence-level (≥ 3σ global) only | Frozen repeat with more membranes of the implicated type; independent analysis team |
| C3-G positive, DFM null | Pivot to gas permeation; vary target isotopes and multilayer period; add telescopes on the C3-G entry side |
| C1 positive (heat + ⁴He), DFM null | Move the C1 lot and waveform into H-L DFMs (same lot, same waveform) to test at a detector-visible location |
| All null | Publish in-regime limits (§10) as magnitude limits, not a refutation. Continue only with claimant-lineage materials (nanocomposite) or new claims |
| Hardware failure | Fix per §11; fallback is a vacuum front with 25 µm Pd on a finer grid (M3 baseline), accepting that the entry face becomes invisible |

## 14. Traceability

| Parameter | Value | Source |
|---|---|---|
| Objective | claim-conditioned, multi-sample | ADR-003 |
| Platform | DFM + C3-G + C1 | ADR-002 rev 2; ADR-005 §2.5 |
| Thickness | 12 ± 1 µm | ADR-005 §2.2 (1A-P4, P6) |
| Single-regime membranes | H-L, H-M, FX | ADR-005 §2.1 (1A-P2, P3; 1D-D1, D2) |
| All-metal cell, Pt annulus, Au seals | — | ADR-005 §2.3 (1A-P1) |
| 8 membranes, 2 lots, staging | — | ADR-005 §2.4 (1C-S2; 1D-D3) |
| T1/T3 inference, blinding | pre-registration v1 | ADR-005 §2.6 (1C-S1 to S16) |
| Controls | T-Pt primary; T-H isotope check | 1A-P5; 1C-S3, S4, S9 |
| Protocol changes | cathodic steps, 42 d, P4, P6a | ADR-005 §2.7 (1D-D6 to D13) |
| Anode gap, electrolyte | 4.0 mm, 1.0 M LiOD | M2 rec. 7 |
| Telescope | 25/500 µm at 4 mm, quadrants | M5 rec. 1 |
| He | two channels, HR-QMS, melts | M8 |
| Calorimetry | SEEB1\* | M4 |
| Positive controls | ⁶LiF calibration membranes, ¹⁰B on B, exempt sources | ADR-004; 1A-P4, P8 |
| γ station, modulation | NaI well, separate Pb stand; P = 12 τ_eff with current steering | ADR-006 (M7) |
| D balance, pressure hierarchy, grid, bond, thermal, Si protection, budget | recycle loop; 0.30 mm grid; press bond; jackets | ADR-007 (1B-B1 to B18) |

## 15. Open risks (for iteration-2 red team)

1. **The H-L loading ceiling.** A "typical" surface gives x ≈ 0.87 at 300 mA cm⁻² (M2). Lot screening and P0b are the gates. A recombination poison is held as an iteration-2 variant.
2. **Bond qualification** (1B-B7). If it fails, the fallback is iteration-1 §13.
3. **Si in 0.5 bar D₂ for ~16 weeks.** The soak telescope decides; the fallback is the SiNₓ/Ni window pocket.
4. **D₂ recycle loop.** It is a new subsystem in the He-tight envelope: bellows-pump reliability, and He blank with the loop running.
5. **γ station.** Its background normalisation (hadronic, ×3) is only fixed by its 14-day blank.
6. **Cost and effort:** ≈ $1.0–1.5M plus 3–4 FTE for Tier 1. The minimum subset (≈ $0.45–0.6M) is the rational first purchase.
7. **Red-team-1B remaining minor items** (B14–B18) are adopted in ADR-007 but are not yet in the CAD model at full detail.

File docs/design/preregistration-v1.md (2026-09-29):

# Pre-registration v1 — DFM-8 (iteration-1 rev B)

**Status:** draft to be frozen. Before P1 of stage 1 it must become a signed git tag `prereg-v1` plus an OSF registration. After that, amendments are allowed only before unblinding, dated and justified, and unblinding is irreversible.
**Basis:** red-team-1C §A–B (adopted with the ADR-005 modifications).

## 1. Units and analysis sets

- **Unit of replication:** the *membrane*. Quadrants are sub-units: they share entry face, electrolyte, current and lot.
- **Active membranes:** 8, in two stages of 4 (ADR-005 §2.4).
- **ITT set:** all membranes that complete P1.
- **Per-protocol set:** membranes with ≥ 14 d of P2 live time at x ≥ 0.90 by rim van der Pauw. The R(x) calibration is frozen from sibling coupons in P0b. For FX membranes the condition is "J within the P0b-predicted band".
- The **primary analysis uses ITT**. Both sets are reported.

## 2. Primary family

Graphical weighted Bonferroni with α-propagation. Global one-sided α_G = 2.87×10⁻⁷ (5σ).

| Test | Weight | Data | Statistic | Background model | Threshold |
|---|---|---|---|---|---|
| **T1 (H1a)** | 0.4 | P2, current-on, **all active membranes and quadrants pooled** (one test). ΔE–E PID window 1.41–3.10 MeV. Clusters of ≥ 2 events within 10 s in one detector count as one event | Poisson profile-likelihood ratio, s ≥ 0 | Pooled: B telescope, T-Pt (4 quadrants), P0a pre-run, FX current-off blocks (≥ 25 % of FX P2 live time), and pre-/post-run blocks of H membranes. One scale nuisance per component. Global log-normal nuisance with σ = ln 3. Background exposure ≥ 10× signal live time | p ≤ 1.15×10⁻⁷ (5.18σ) **and ≥ 10 net events** |
| **T3 (H2)** | 0.4 | ⁴He from front volume and headspace, over all P2–P4 windows. Summed per cell, then over the active cells. Quadrant melts form a pre-specified second component | Σ_cells (N_obs − N̂_blank,cell) / σ_tot. σ_tot combines each cell's blank-series variance with the between-cell variance measured in P0a. A D₂-matrix spike correction is applied per aliquot class | Each cell's own blank series (≥ 3 × 1 d and ≥ 2 × 7 d, taken both pre and post); sibling coupons for the melts | p ≤ 1.15×10⁻⁷ (5.18σ) |
| **T2 (H1c)** | 0.2 | γ station (ADR-006): 12–30 MeV summed-deposit and 511-coincidence rates, steering-on vs steering-off, D₂O blocks vs H₂O blocks (5-day alternation) | Joint on/off likelihood of both channels, with the MC-fixed ratio between them (M7 §5.8) | 14-day Au-foil blank; H₂O blocks; off half-periods | p ≤ 5.7×10⁻⁸ (5.30σ) |

- **α-propagation:** if any primary test rejects, its α is split equally between the others.
- **T4 (C3-G transmutation):** a separately registered study with its own α. Its primary endpoint is ¹⁴¹Pr from ¹³³Cs, measured by blinded two-lab ICP-MS and ToF-SIMS on coded samples. The reach is stated as isotope-ratio precision.

## 3. Conditions for a discovery claim

All of the following are required. Each is one-sided and fixed now.

1. **Primary test.** A primary test rejects at its threshold.
2. **Flux or loading dependence, on independent data.**
   - FX membranes: P3 lock-in at the frozen period (P = 12 τ_eff from P0b, clipped to 1–6 h), with current steered to the auxiliary cathode and the exhaust mass-flow exit flux as the single regressor, gives ≥ 3σ in the same channel.
   - H membranes: P3 cathodic step response, with the same frozen parameters.
   - In both cases, the current-off blocks must be consistent with background: 95 % upper limit < 25 % of the P2 rate.
3. **Replication.**
   - ≥ 2 membranes, each ≥ 2σ locally, from ≥ 2 lots.
   - Heterogeneity χ² across membranes not rejected at p < 0.01.
   - No single cluster or day contributes > 20 % of events.
4. **Signature.**
   - The ΔE–E distribution is consistent with protons from 0–12.5 µm depth (response-matrix unfold, ⁶LiF-calibrated; KS p > 0.01).
   - It is inconsistent with the sideband shape (p < 0.01).
   - Triton and ³He rates are consistent with the proton rate where kinematically accessible.
5. **Controls.** T-Pt, T-H(L), T-H(FX) and B each have a 95 % upper limit per quadrant-exposure below 25 % of the active rate.
6. **Blind integrity.** The salts are recovered within ± 2σ before the box is opened, and the two analysis teams agree within 1σ.
7. **Neutron statement.** M5's pre-registered sentence ("protons below ~10⁻² fusions s⁻¹ appear without detectable neutrons") is evaluated. It is not used as a veto.
8. **Heat.** Any heat statement additionally requires the mass-flow cross-check (M4 rec. 12). Particle products below the calorimetric floor carry no heat claim.

## 4. Reporting tiers

- **Evidence:** a primary test at global ≥ 3σ.
- **Claim:** all conditions in §3 are met.
- **Descriptive only:** per-skin, per-quadrant, per-lot and per-variant results (Al additive, SuperWave), plus neutron, heat, AE, triton/³He lines, and γ-station results other than T2. These are reported with Feldman–Cousins intervals and no significance language.

## 5. Null reporting (committed)

- For every claim in the ADR-003 register, publish Feldman–Cousins 90 %/95 % upper limits, normalised per area and per volume with the scaling stated, whatever the outcome.
- State plainly that an all-null outcome is a magnitude limit conditional on reaching the regime. Its Bayes factor against existence is ~1.4–1.6, and it is **not** a refutation.
- Submit as a registered report where the journal allows it. Release list-mode data, waveforms, He raw data and code at unblinding.

## 6. Stopping and failures

- **Fixed durations per stage:** P2 = 42 d, P3 = 14 d, P4 = 14 d, P6a = 2 d.
- **Interim unblinded looks:** safety only (neutron bank at 10× background, pressure and Δp, temperature).
- **Membrane failure:**
  - before P2: replaced under a new ID;
  - after P2 starts: data truncated at the last DQ-good period, and no replacement enters the primary analysis.
- **Extensions:** none conditioned on data. Any extension is decided on DQ grounds only, by the custodian, blind to box counts.
- **Stage 2:** its allocation is frozen and registered as amendment A1 before stage-1 unblinding.

## 7. Frozen data-quality cuts

These are tuned on P0a, blank-telescope and sideband data only.

- Veto ± 1 s around current edges.
- ΔE leakage-current and noise-rms thresholds.
- Muon-veto coincidence.
- Pulse-shape χ² against pulser templates.
- Cluster flag.
- AE-coincident events (± 50 ms) flagged. They are included in T1, and reported separately as the H1b tag.
- He aliquot acceptance: spike recovery within ± 10 %.

## 8. Blinding and salting

1. **Custodian.** One person, outside the analysis team, holds the cell → channel map (T-H and T-Pt among the active labels), the salt file and the He aliquot codes.
2. **Box.** PID-window events of all channels are hidden. Analysts see sidebands, B, the calibration-marker windows and the live time.
3. **Software salt.** Synthetic ΔE–E events are drawn from the ⁶LiF-validated response. They are injected into 0–2 random channels at {0, 0.5, 1, 2} × the median 5σ reach, with Poisson timing and a random current-on fraction.
4. **Hardware salt.** The ADR-004 source boost (at a partner facility) or cosmic ¹⁰B markers, toggled on the custodian's schedule.
5. **He.** Aliquots are coded. ≥ 20 % are blanks, and ≥ 2 hidden ⁴He spikes of 5–10 σ_B are included.
6. **Two analysis teams.** Independent code bases. At least one external member, ideally a known skeptic.

## 9. Pre-computed reach

`sim/design_iter1_reach.py` (output `figs/iter1_reach.txt`) gives the following for T1, P2 of 42 d at 0.8 live fraction, α = 1.15×10⁻⁷, with the ≥ 10-net-event floor:

| Background per cell (d⁻¹) | Single membrane, exit face | Single membrane, entry face | Pooled 8, per membrane (exit / entry) |
|---|---|---|---|
| 0.03 | 8.7×10⁻⁵ | 1.2×10⁻⁴ | 2.0 / 2.7 ×10⁻⁵ |
| 0.09 (3× band) | 1.1×10⁻⁴ | 1.5×10⁻⁴ | 3.1 / 4.2 ×10⁻⁵ |

Units are D+D fusions s⁻¹. The inputs are:
- ε = 0.22 (exit) or 0.162 (entry), × 0.43 grid transmission (0.30 mm Mo, ADR-007) × 0.9 septum loss;
- a proton branch of 0.5.

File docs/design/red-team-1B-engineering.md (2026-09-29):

# Red-team 1B — Engineering, buildability and safety review of iteration-1 rev B

**Scope:** `docs/design/iteration-1.md` (rev B), `docs/decisions/ADR-005-iteration1-revB.md`, with the M2/M3/M4/M5/M8 models and R6.
**Numbers:** `sim/rt1b_checks.py` → `docs/design/figs/rt1b_checks.txt`, `rt1b_checks.png`. Values tagged [est.] are engineering estimates that were not taken from a source.
**Date:** 2026-09-29

## Summary verdict

**Rev B cannot be built and run as drawn.**

**The fatal problem is the gas balance of the closed cell, which no document has worked out.**
- Every deuterium atom that enters the membrane leaves an excess O₂ at the anode. The recombiner then burns headspace D₂ to remove that O₂.
- **Loading.** Bringing one 12 µm foil to x = 0.9 burns 69 % of the 306 µmol headspace D₂. Cell pressure falls from 500 to ≈155 mbar. The reverse-relief foil (20 mbar) bursts during P1 in every cell.
- **FX and H-M cells.** Permeation empties the headspace D₂ in 2–31 min. After that, O₂ builds up **while the pressure falls**, which the R6 "ΔP ≥ +10 %" trip cannot see. The same cells lose 12–177 g of D₂O over P2, from a 13 g inventory.
- **No make-up path exists.** The design has no He-free D₂ make-up path to the cell. Even an ideal Pd-purified make-up supply (He fraction 10⁻¹⁵) puts 10²–10³ He s⁻¹ into the headspace channel, above its 43–100 He s⁻¹ floor.

**The pressure-protection hierarchy is inverted.**
- The cell burst disk (3.5 bar) sits far above what the membrane and grid can take (≈0.5 bar ΔP).
- The 0.10 mm Mo grid reaches 258–516 MPa in the specified loss-of-front cases, and 1–2 GPa if its "ribs" are only in-plane.
- The P3 FX protocol breaks the membrane in two ways:
  - it pulls 1.4× the foil's D inventory per anodic half-cycle, over 5,040 cycles;
  - its 0.2↔1.0 bar front steps conflict with the ±40 mbar interlock.

**Secondary but real:**
- The bonded Pt annulus shunts the rim van der Pauw gauge. Loading sensitivity drops from 80 % to 14 %, so 1 K of drift is worth 3 % of the whole loading signal.
- "22 ± 1 °C" can only be a jacket set-point. The electrolyte runs 3–8 K above it at 200–300 mA cm⁻² and 11–19 K above at 500 mA cm⁻².
- The house needs internal water cooling: +64 K otherwise.
- The He floors are targets, not credible design values, until P0a blanks show them.
- The budget omits or underprices valves, gauges, sector-MS samples, custom Si and ³He tubes. A realistic DFM-8 costs ≈ $0.8–1.5M, not $0.415M. The 8-month schedule leaves out 6–10 months of procurement and development.

**Every Critical item below has a concrete fix.** None requires leaving the COLD envelope.

## Ranked findings

| ID | Sev | Finding | Quantitative evidence | Fix |
|---|---|---|---|---|
| **B1** | **Critical** | Closed-cell D balance. Loading and permeation consume headspace D₂ through the recombiner. There is no make-up path, O₂ enriches at falling pressure, and D₂O runs out | Loading to x = 0.9: 422 µmol D ⇒ 211 µmol D₂ burned = 69 % of the headspace; P_cell 500 → 155 mbar (ΔP −345 mbar vs foil −20). H-M 10 / FX 50 / FX 150 mA cm⁻²: headspace D₂ gone in 31 / 6.3 / 2.1 min, dP/dt −0.4 / −2 / −6 mbar s⁻¹, then O₂ at 0.08–1.2 µmol s⁻¹. D₂O loss 0.28 / 1.4 / 4.2 g d⁻¹ vs 13 g inventory | (1) Active cell-side pressure control with **He-free D₂ make-up**: recycle the front's Pd–Ag exhaust into the headspace through a metal-bellows pump, or use a dedicated electrolytic D₂ generator permeating through Pd. (2) A **two-sided** trip: low pressure at −10 % of fill plus a direct O₂ measurement (QMS m/z 32/36 on a headspace sniff, or a sealed electrochemical O₂ cell). (3) Liquid-level sensor. (4) Declare the headspace ⁴He channel **descriptive only on FX/H-M**: make-up adds ≥ 10²–10³ He s⁻¹ even at a 10⁻¹⁵ He fraction. The front channel is unaffected |
| **B2** | **Critical** | Overpressure hierarchy inverted: the membrane and grid are the weakest boundary, but the only cell relief is 3.5 bar | Loss-of-front at 0.5 bar is already 28 MPa (membrane) and 258 MPa (grid). An isochoric deflagration of the headspace reaches 8–10 × P₀ = 4–5 bar (R6 §3), far beyond both. The ruptured membrane then passes gas and electrolyte to biased Si and a 350 °C Pd–Ag element, which acts as an H₂/O₂ catalyst | Add **forward relief** from the cell to a vent line at ΔP ≤ +150 mbar (sized from the grid rating after B3). Add a front burst disk to vent. A Δp or m/z 20 trip must **isolate and de-energise the Pd–Ag element and cut cell current**. Rate each boundary in a written pressure-hierarchy table |
| **B3** | **Critical** | The Mo grid (0.10 mm, open fraction 0.80) is ~2× undersized for the loss-of-front cases the design itself invokes (P6a pumps the front for 2 d) | Ligament efficiency 0.09. σ = 15 / 258 / 516 MPa at +30 mbar / 0.5 bar / 1.0 bar with 5 mm cells, or 62 / 1031 / 2062 MPa if the ribs are in-plane only (10 mm cells on the septum). Mo yield: 550–700 MPa stress-relieved, 350–450 MPa recrystallised; DBTT ≈ RT [est.] | Use the M3 spec: a 0.3 mm sheet (40 MPa at 1 atm), or ribs **≥ 1 mm deep** under the existing septum shadow and at the 5 mm pitch. Proof-test each grid at 1.5 bar. Forbid recrystallising heat treatment of the grid |
| **B4** | **Critical** | The P3 FX protocol is mechanically incompatible with the mount | (a) Front steps 0.2↔1.0 bar with the cell at 0.5 bar give 500 mbar reverse ΔP on a lifted membrane: 251 MPa > UTS 170. If balanced, both volumes must track to ±20 mbar over an 800 mbar step (2.5 %) while B1 is also acting. (b) The −100 mA cm⁻² anodic half-cycle (120 s) pulls 12 C cm⁻², 1.4× the foil inventory at x = 0.65. The entry face therefore crosses α/β on each of 5,040 cycles, against an M3 perforation life of 12–180 transits | (a) Specify **balanced** ramps ≤ 1 mbar s⁻¹ run by one controller that commands both volumes, with the trip referenced to ΔP. (b) Cap the anodic charge at ≤ 10 % of inventory per half-cycle (e.g. −100 mA cm⁻² for ≤ 8 s, or −10 mA cm⁻²). Pre-register an `m3_cycling` run showing x_entry ≥ 0.60 throughout |
| **B5** | **Critical** | The Δp interlock logic cannot keep FX/H-M cells intact through a routine fault. Its bands overlap the operating window | Operating band +10…+50 mbar vs trip ±40. Thermal: 3.1 mbar K⁻¹ (gas 1.7 + D₂O vapour 1.4), so a 500 mA cm⁻² step moves ΔP ≈ 31 mbar. With the Pd–Ag exhaust stopped (heater or mains loss), the front rises 2.0 / 0.67 / 0.27 / 0.13 mbar s⁻¹ (FX 150 / FX 50 / keep-alive 20 / H-M), and the relief foil bursts in **25 / 75 / 188 / 376 s**. The trip action, "close valves", makes an FX front rise faster | Trip action for all cells: **galvanostat to 0 on FX/H-M**; open circuit leaves FX at x ≈ 0.65, its operating state, and H-L drops to keep-alive. Put the Pd–Ag heaters, the pressure controllers and the PLC on the UPS. Re-derive the bands: operate +30 ± 10, alarm ±15, trip at +5 / +60 mbar. Add cell-temperature feed-forward to the ΔP set-point |
| B6 | Major | The rim van der Pauw gauge sits over the bonded Pt annulus, which carries most of the current | 2-D finite differences (contacts at Ø21): ρ_Pd × 1.8 changes R_vdP by **14 %** with the annulus vs 80 % for Pd alone. The Pt TCR (0.39 % K⁻¹) makes 1 K equal to 3 % of the full loading signal. Near x = 0.9, Δx = 0.01 ≈ 0.5 K. The "x ≥ 0.90 in-regime hours" gate is therefore unmeasurable | Keep the Pd–Pt bond **outside** a Pd-only rim of ≥ 1.5 mm and put the contacts there, or add 4-wire Pd tabs that extend beyond the annulus. Calibrate R(x) on **bonded** sibling assemblies. Thermostat the rim to ±0.05 K and log it |
| B7 | Major | A diffusion bond at 850 °C/1 h under a "light dead-weight" is not credible as a He-tight, fatigue-resistant joint on 12 µm foil | Pd self-diffusion at 1123 K: D ≈ 9×10⁻¹⁸ m² s⁻¹, so √(Dt) ≈ 0.2 µm in 1 h. That is below the asperity heights of rolled foil (0.1–1 µm). Diffusion bonding needs ~5–20 MPa contact pressure [est.]; a dead-weight gives kPa. The bond then sees ≈ 3.3 % hydride misfit (≫ yield) once per full load/deload, and the bond edge is a stress singularity. The front gas (0.5 bar) loads the rim to x ≈ 0.65 whatever the PTFE does | Bond in a press with ceramic platens at 5–10 MPa, or add a sputtered Pt/Au interlayer and thermocompression. **Qualification before any cell:** ≥ 10 coupons; He leak ≤ 10⁻¹¹ mbar L s⁻¹ before and after 3 full D load/deload cycles; peel and cross-section. Budget 6–8 weeks and $15–25k. Keep the fallback (iteration-1 §13) ready |
| B8 | Major | Thermal: 22 ± 1 °C is achievable only as a jacket set-point, and the heat path is not in the design. The house has no heat sink | G_liner = 0.60 W K⁻¹ (24 cm² of 1 mm PTFE). ΔT = 3–8 K at 200–300 mA cm⁻² and **11–19 K at 500 mA cm⁻²** (V_cell 4.1–7.3 V with 27–60 % void; Q 6.5–11 W). τ ≈ 100 s. An unjacketed body (free convection, 0.10 W K⁻¹) would run +36–80 K. The house carries ≈ 230 W inside 20 cm of HDPE (3.6 W K⁻¹), so +64 K. The P3 steps put a current-locked temperature (and Si leakage) swing onto the lock-in channel | Water-jacket each body. Put an electrolyte RTD in a PTFE-sheathed thermowell and servo with I·V feed-forward. Run a chilled loop inside the house. Thermostat the Si mounts separately and log leakage current as a pre-registered nuisance covariate. Pre-register the electrolyte-temperature definition. For Seebeck cells, accept a floating electrolyte temperature and report it |
| B9 | Major | The He floor (0.16–0.39 nW = 43–100 He s⁻¹) depends on leak and valve performance that the build cannot verify before P0a | Air in-leak: 10⁻¹² std-He total gives 129 He s⁻¹. Keeping the leak ≤ 10 % of the floor needs ≤ 3×10⁻¹⁴ mbar L s⁻¹ over all seals, below He-leak-detector reach (Ar route only). One closed valve seat facing a manifold at 10⁻⁶ mbar He after a spike gives ≈ 2,500 He s⁻¹. The headspace side alone carries lid, anode feedthrough, P, T, burst disk, sample valve and relief foil. The ≤ 10-seal budget is already spent | **Pumped (or Ar-guarded) interspace on every demountable seal.** Put a 3-valve pumped-interspace isolation between the manifold and each cell. Do a seal-count audit per volume. Set a P0a acceptance rule: floor ≤ 3× target, otherwise the cell runs as descriptive. Pre-register the fallback reach at a 10× floor, which is still ~10⁻⁷ of the claims |
| B10 | Major | Si in 0.5 bar D₂: margins are thin and there are no long-term data | Paschen minimum ≈ 300–330 V at pd ≈ 2.5 Torr cm, so 150 V gives a ~2× margin, eroded by bond-wire edge fields and by Kr (Penning). P6a pump-down crosses the minimum. The 25 µm ΔE as a diaphragm (a = 12 mm) reaches 13 / 61 / 178 MPa at 10 / 100 / 500 mbar across it. ΔE capacitance is 624 pF per quadrant, so 7–11 keV rms noise (acceptable). At 60 °C (P4), leakage rises ~30× | Interlock bias off for 0.05–50 mbar and during any ramp > 5 mbar s⁻¹. Vent the ΔE–E gap (≥ 2 mm² per quadrant). Soak a sacrificial telescope in D₂ from P0a onward. **Fallback:** Si in a separate vacuum pocket behind a **2 µm Ti window on an aligned twin grid** (≈ 92 MPa at 0.5 bar vs Ti yield ≥ 300; ΔE_p ≈ 60–90 keV). This also protects the Si from B11. The vacuum front for H-L stays as the second option |
| B11 | Major | Membrane rupture sends LiOD onto biased Si faster than any interlock can act | A 1 mm hole at 34 mbar (30 + 4 mm liquid head) passes ≈ 2 mL s⁻¹ and reaches the ΔE in < 1 s. LiOD etches Si, shorts the HV and destroys the telescope. Headspace gas (O₂ ≤ 3 %, more in the B1 case) reaches the hot Pd–Ag | Current-limit the HV (≤ 1 µA, µs trip). Budget ≥ 2 spare telescopes. Adopt the window fallback in B10. Isolate and cool the Pd–Ag on an m/z 20 or Δp trip |
| B12 | Major | Budget is missing or mispriced | See §6: all-metal valves ≈ 60 × $1.5–3k; 24 capacitance gauges; external sector-MS ≈ 560 samples × $0.5–2k; custom epoxy-free quadrant telescopes $10–15k each plus NRE; new ³He tubes $3–8k each; ≈ 60 digitiser and preamp channels; chillers and jackets | Re-baseline DFM-8 at ≈ $0.8–1.5M and Tier 1 at ≈ $1.0–1.7M, excluding labour (3–4 FTE × 1.5 y). Keep HR-QMS as primary and use the sector MS only on a pre-registered subset (≤ 60 samples) |
| B13 | Major | Schedule: "two stages ≈ 8 months" is run time only | Custom Si lead time 16–26 wk; bond development 6–8 wk (B7); He-system commissioning; stage-2 rebuild needs bonding + bake + ≥ 3 × 1 d + 2 × 7 d blanks = ≥ 17 d per cell. P0b fixes the Ni thickness **after** H-M (stage-1 A3) must already be installed for P0a blanks | Plan 15–20 months to the end of stage 2. Run P0b on a separate bench **before** stage-1 assembly, or build stage-1 A3 as H-L |
| B14 | Minor | Transformation plasticity when α↔β transits happen under load | ε_tp ≈ 1.2 % (P1 at +30 mbar); 1.6–5.8 % (P6a at 0.5 bar, hardened/annealed); 2.4 % (after P4 at 1.0 bar). The foil dimples into the 1 mm holes and thins at hole edges | Hold ΔP ≤ +10 mbar during P1 and P6a transits. In P6a, lower the cell to ≤ 50 mbar before pumping the front |
| B15 | Minor | Pt corrugation and the PTFE-liner edge | Guided-leg strain 0.75 % at 0.45 mm travel, far above annealed-Pt yield, so it ratchets on each full cycle (few cycles, acceptable). As a diaphragm it reaches 22 / 45 MPa at 0.5 / 1.0 bar, against a yield of 35–50. The PTFE-vs-316L CTE gives ≈ 0.16 mm liner movement over the 38 K of P4: the liner lifts off the foil, electrolyte creeps to the rim and bond, and the Pt becomes cathode area | Use 0.15 mm Pt, or two convolutions. Spring-load the liner onto the foil (Au-plated wave spring). Accept the Pt rim as cathode area and correct j |
| B16 | Minor | P4 at 60 °C | D₂O vapour ≈ 0.17 bar plus 13 % gas expansion trips the "ΔP ≥ 10 % of fill" rule. The plateau at 60 °C is 0.20 bar, so FX drops to x ≈ 0.59 | Re-zero the trip at temperature with a pre-registered ramp (≤ 5 K h⁻¹) and an O₂ sensor (B1) covering the re-zero window. Keep the Si at ≤ 30 °C |
| B17 | Minor | Burst foil at 20 mbar reverse | Commercial low-pressure disks have ±25–50 % tolerance. A foil that bursts at 30 mbar gives 38 MPa on the lifted membrane, ≈ the annealed yield. The foil sees +30…+50 mbar forward continuously | Reverse-acting disk with vacuum support, tolerance ≤ ±5 mbar, qualified by lot. Log its He contribution as a seal (B9) |
| B18 | Minor | He from the electrolyte and PTFE | Air-saturated D₂O holds ≈ 4.6×10⁻⁸ cm³STP g⁻¹, so ≈ 1.6×10¹³ He in 13 g. This must be stripped by ~10⁻⁷ before the first window. PTFE He diffusion time over 1 mm is ~10³ s, so the 150 °C bake empties it. Neither drives the floor if blanks are taken after the fill | Sparge ≥ 30 min, then take the P0a blanks **after** the fill (not on a dry cell) |

## FMEA (top 10)

S = severity, O = occurrence, D = detection difficulty (1–10); RPN = S·O·D.

| # | Failure mode | Cause | Effect | S | O | D | RPN | Mitigation (see finding) |
|---|---|---|---|---|---|---|---|---|
| 1 | O₂-rich headspace at falling pressure | Permeation or loading consumes D₂ via the recombiner; no make-up (B1) | Flammable mixture in a 15 mL headspace above a 12 µm wall; deflagration ruptures the membrane | 9 | 9 | 7 | **567** | D₂ make-up, two-sided trip, O₂ measurement |
| 2 | Relief foil burst or membrane lift in P1 | Cell pressure falls 345 mbar during loading (B1) | Loss of both He channels for the cell for the stage | 7 | 10 | 3 | 210 | Make-up and ΔP servo during P1 |
| 3 | FX cycling fatigue and perforation | Anodic half-cycle > inventory; 5,040 cycles (B4) | Pinholes, electrolyte to Si, H1b cracking confound | 7 | 7 | 5 | 245 | Cap the anodic charge; simulate before freeze |
| 4 | Spurious ⁴He via valve seats, spikes, leaks | Manifold spikes, 10⁻¹² class seals (B9) | False T3 positive (scientific severity) | 8 | 5 | 5 | 200 | Pumped interspaces, blind spikes, Ar/Kr tracers |
| 5 | Headspace over-pressure or deflagration | Recombiner flooding, hot spot, or B1 | Membrane and grid fail long before the 3.5 bar disk; hot gas and LiOD to Si and Pd–Ag (B2) | 10 | 3 | 6 | 180 | Forward relief ≤ +150 mbar; Pd–Ag isolation |
| 6 | Grid yield on loss-of-front or P6a | 0.10 mm grid, 258–2062 MPa (B3) | Membrane lift, tear, rupture | 7 | 5 | 5 | 175 | 0.3 mm sheet or deep ribs; proof test |
| 7 | FX front flood on power or heater loss | Pd–Ag exhaust stops; foil bursts in 25–75 s (B5) | Stage loss for the cell; D₂ into the headspace | 7 | 6 | 4 | 168 | UPS on the Pd–Ag and controllers; current-off on trip |
| 8 | Membrane rupture onto biased Si | Bond voids, pinholes, fatigue (B7, B11) | Telescope destroyed, HV short, LiOD in front | 7 | 5 | 4 | 140 | HV current limit, window fallback, spares |
| 9 | Unattended power loss over weeks | UPS sized for galvanostats only | Loss of chillers and heaters, ΔP excursions, dry-out | 6 | 6 | 4 | 144 | UPS scope: Pd–Ag, PLC, gauges, chiller controls; hardwired trips; remote paging |
| 10 | Thermal excursion at 500 mA cm⁻² | Jacket or chiller failure; void-fraction V_cell rise (B8) | +11–19 K with a jacket, +36–80 K without; D₂O dry-out; recombiner > 180 °C | 8 | 3 | 3 | 72 | Hardware over-temperature trip at +5 K; limit excursions to jacketed cells |

Below the top 10:
- ³He tubes at 1–1.5 kV in a closed HDPE house carrying D₂ lines. Without make-up the house holds ≈0.2 L STP of D₂ in a 40 L cavity (≤ 0.5 %). With make-up there is a supply line: fit an excess-flow valve and restrictor outside the house plus an H₂ sensor inside.
- LiOD handling (caustic). Fill under Ar in a glove bag, with a face shield.
- Loaded-Pd stored energy (0.06 kJ) is negligible.

## Details

### 1. Membrane and mount (B3, B4, B6, B7, B14, B15, B17)

- **Membrane stresses are internally consistent.** The ADR-005 figures (28 / 44 / 54 MPa) scale correctly from M3.
- **The problems sit in what carries those stresses.**
  - **Grid.** M3 recommended a 0.3 mm sheet on ribs. Rev B shrank it to 0.10 mm and raised the open fraction to 0.80. Plate stress scales as 1/(t²η), so the grid moved from 40 MPa to 516 MPa at 1 atm.
  - **Ribs.** "0.5 ribs at 5 pitch" is only meaningful if the ribs are deep. As drawn they are wider webs in the same sheet, which leaves the cross septum as the only support.
- **Bond.** The Pd–Pt bond is elegant on paper: no hydride forms on the Pt side. But:
  - a dead-weight cannot close asperities;
  - the Pd *on* the bond still hydrides from the front gas;
  - the bonded Pd/Pt bilayer is plastically cycled at every full load/deload.
- **Low-cycle fatigue.** The few full cycles in the protocol (P1, P6a, possibly P4) are acceptable. The 5,040 FX anodic cycles are not, if they cross α/β at the entry face (§E of the output).
- **Pinholes and leaks.** Pinholes in 12 µm rolled foil, and bond voids, are cell→front leak paths. Kr tracing and the m/z 20 trip detect them; nothing prevents them. Hence the per-foil He leak test before bonding and the bond qualification in B7.

### 2. Si telescope in D₂ (B10, B11)

- **Discharge margin.** 150 V bias sits ~2× below the Paschen minimum. That margin is adequate at 0.5 bar steady state. It is not adequate during P6a pump-down or with Penning admixtures, so bias must be interlocked on pressure.
- **Hydrogen effects.** Molecular D₂ at RT does not dissociate on SiO₂/Al, so B–H passivation and interface-trap changes should be small. There are, however, **no months-long data** for PIPS detectors in D₂. A sacrificial soak telescope costs one device and removes the unknown.
- **Recommended fallback.** The thin-window vacuum pocket (B10) beats "vacuum front for H-L":
  - it keeps the front D₂ ambient for all membrane types;
  - it isolates the Si from rupture;
  - it avoids 28 MPa sustained on the membrane.
  The cost is ≈60–90 keV of proton energy and a co-aligned second grid.

### 3. Cell (B1, B8, B15, B16, B18)

- **Geometry.** The 12 mL electrolyte forms a 38 mm column in a 20 mm bore. Liner conduction (0.60 W K⁻¹) is the heat path, and the electrolyte time constant is ≈100 s.
- **Void fraction in the 4 mm gap.** At 0.5 bar the gas volume doubles relative to 1 bar. Void fraction is 0.16–0.60 at 300 mA cm⁻², depending on bubble size (50–100 µm, Stokes rise). Cell voltage is 3.1–5.2 V at 300 mA cm⁻² and 4.1–7.3 V at 500 mA cm⁻².
  - SELV holds.
  - The "≤ 3.2 V at 200 mA cm⁻²" line holds only for ≥ 100 µm bubbles.
  - Measure V_cell on the P0b witness.
- **Recombiner.** Load is 0.96 / 1.44 / 2.40 W at 200 / 300 / 500 mA cm⁻². The headspace turns over every ≈40 s at 300 mA cm⁻². A 1 % recombiner lag gives +0.12 mbar s⁻¹, so the ΔP servo in B1/B5 is needed even for H-L cells.
- **Carbonate.** Negligible once sealed. Fill under Ar.

### 4. He system (B1, B9, B18)

- **The Pd–Ag element.** It is He-tight as a solid. Its risks are pinholes, braze joints and the upstream He content. With the exhaust facing vacuum, a pinhole leaks outward, which is harmless. The fill direction needs a Pd–Ag-purified source.
- **The make-up flow B1 requires** (0.3–4.7 L STP d⁻¹) makes the headspace channel of FX/H-M cells unusable at the stated floor, even at a 10⁻¹⁵ He fraction.
- **Shared manifold.** It needs pumped-interspace isolation per cell, as M8 already specifies for pipettes.
- **Floor credibility.** The M8 floor (σ_B ≈ 7×10⁵ atoms d⁻¹) is about 10× below typical cold line blanks reported by noble-gas labs (~10⁻¹² cm³STP ≈ 3×10⁷ atoms per extraction) [est.]. Treat 0.16–0.39 nW as a target to be earned in P0a. Pre-register the 10× floor as the planning case.
- **Bake.** With Si inside, bakes are limited to ≤ 100 °C [est.], as M8 notes. This does not limit He, but it leaves more H₂O/D₂ load for the getters.

### 5. Safety

The FMEA is above.

- **The single most important safety change is B1.** The rev-B trip philosophy, inherited from R6, assumes stoichiometric gas production. A permeating cathode breaks that assumption and turns pressure *loss* into the hazard signal.
- **B2 inverts the relief hierarchy.** The membrane is the de facto burst disk, and it bursts toward biased electronics and a hot catalyst.
- **P6a (front pumped).** It is the designed loss-of-front case. Do it only after B3 is fixed, and with the cell brought down to ≤ 50 mbar (B14).
- **P4 (1.0 bar, 60 °C).** It needs the trip re-zeroed and O₂ monitoring (B16).
- **UPS scope must include:**
  - Pd–Ag heaters;
  - pressure controllers;
  - the PLC;
  - chiller control.
- **Hardwired trips.** Every trip must act in hardware, per R6 #16.

### 6. Budget and schedule (B12, B13)

| Item | Rev-B line | Realistic [est.] |
|---|---|---|
| All-metal valves (≈ 6 per cell × 8 + manifold ≈ 60) | inside $30k "gas and He" | $90–180k |
| Capacitance and Δp gauges (3 per cell × 8) | same | $50–70k |
| Pd–Ag elements (9), NEGs, ion/turbo pumps for the manifold | same | $30–50k |
| Make-up/recycle loop (B1), per cell | none | $5–10k × 8 |
| Si telescopes, custom epoxy-free quadrant ΔE + E, NRE, 2 spares | $48k | $110–160k |
| Digitisers and low-noise preamps (≈ 60 channels) | $35k | $80–120k |
| ³He bank, 24 new 4-atm tubes plus electronics | $65k | $100–200k |
| Jackets, chillers, house cooling | none | $25–45k |
| External sector-MS (7 He cells × 2 channels × ~20 windows × 2 stages ≈ 560 samples) | inside $45k | $0.28–1.1M if all go to sector MS; ≈ $60k if limited to a pre-registered subset |
| Bond development and qualification (B7) | none | $15–25k |
| **DFM-8** | **$415k** | **≈ $0.8–1.5M** |

- **Labour** is excluded throughout, but it is the dominant cost: 3–4 FTE for ≈1.5 years.
- **The $0.28M minimum subset** carries the same valve, gauge and He-analysis underpricing. It is realistic at ≈ $0.45–0.6M.
- **Schedule.** The 8 months counts run time only. Procurement, bond development and He commissioning add 6–10 months, so plan **15–20 months** to the end of stage 2.
- **P0b sequencing** must move before stage-1 assembly (B13).

### 7. What was checked and found adequate

- **Stored energy.** 0.06 kJ in the membrane and ≤ 50 J in a stoichiometric 15 mL at 0.5 bar.
- **SELV** at ≤ 7.3 V.
- **Pd–Ag exhaust area** for FX 150: ≈ 1.2 cm², which is feasible.
- **Recombiner heat** through the lid.
- **ΔE noise** of 7–11 keV rms against a 0.3–0.6 MeV proton ΔE deposit.
- **Corrugation fatigue** under H-cell P3 steps (Δx ≈ 0.03 ⇒ ≈ 15 µm radial, elastic).
- **Loss-of-front membrane stresses** at 0.5 / 1.0 bar (28 / 44 MPa, once hardened by the first transit).

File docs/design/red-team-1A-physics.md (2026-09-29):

# Red-team 1A — Nuclear / condensed-matter physics review of iteration-1 (DFM-4)

**Scope:** `docs/design/iteration-1.md` against the charter, ADR-002 rev 2, ADR-003, ADR-004 and M0–M8.
**Reproduce:** `python3 sim/rt1a_physics.py` writes `docs/design/figs/rt1a_physics.txt` and `figs/rt1a_tomography.png`. The script reuses `m5_stopping`, `m5_si_telescope` (geometry, deposit, PID) and `m3_common` (isotherm, Kirchhoff potential).

## Summary verdict

At normal incidence the charged-particle arithmetic is correct: 3.015 / 2.54 / 2.00 MeV for exit / mid / entry protons through loaded PdD₀.₉ plus 4 mm of 0.5 bar D₂. The physics built around those numbers has three serious problems.

1. **The ⁴He channel is compromised by the cell's own materials.** A PCTFE cell body and an FFKM rim seal put polymer He permeation and outgassing 10⁶–10⁷× above the quoted 0.16–0.39 nW floors in the headspace channel, and 10²–10⁵× above them in the front channel through cell→front crossover. The effect is temperature-dependent, so the P4 warm phase manufactures a correlated heat/He artifact. M4 §5.10 already forbids exactly this.
2. **The "SRI conditions at the entry face" premise holds only under the L and M quadrants.** A bare or oxide exit at 0.5 bar D₂ needs ≈3 A cm⁻² of *absorbed* current to keep x_in = 0.9 across 15 µm. The cell supplies ≤0.15 A cm⁻², so the whole foil under F, X and ED (10 of the 16 rotation slots) sits at x ≈ 0.655, entry face included. The same quadrant structure imposes a 1.6 % in-plane misfit between neighbouring quadrants. That is GPa-level stress against a 40–150 MPa yield, so the foil will plastically deform and crack at the skin boundaries, which is a built-in H1b confound.
3. **The chosen 15 µm thickness breaks the ADR-004 ⁶LiF depth calibration and halves entry-face proton efficiency** relative to what §3.4 implies.

Electrolyte-borne cosmic recoils (n–p in the H₂O twin; n–d and D(n,np) in D₂O) are missing from the background budget and unbalance the D − H control. None of these makes the experiment unbuildable. Findings 1–2 must be fixed before the design is frozen, otherwise H2 and the SRI arm of the claim register score ≈ 0 under ADR-003.

## Ranked findings

| ID | Sev. | Finding | Quantitative evidence | Concrete fix |
|---|---|---|---|---|
| **P1** | **Critical** | Polymer He sources: the PCTFE cell body and the FFKM rim seal swamp both ⁴He channels | Air→cell through PCTFE (71 cm² × 5 mm, 1–30 Barrer): **1.5×10⁸–4.5×10⁹ He/s**. FFKM seal if air-exposed: 1.7×10⁸ /s. Stored air-He in ~36 cm³ of polymer: 1×10¹⁴ atoms (~2×10⁸ /s over ~5 d). Cell→front crossover via FFKM: 10⁴–10⁷ /s. **Floor: 43–102 He/s.** The Kr tracer does not bound He permeation through polymers | All-metal cell: PTFE-*lined* 316L, as in M4 §5.10. Replace the FFKM with a metal seal to a non-hydriding rim (P1-fix in §P1). Bake and pump-purge polymer liners, and run ≥2 blank windows after the fix |
| **P2** | **Critical** | Under F/X/ED the entry face is at x ≈ 0.655, not ≥ 0.9. SRI/ENEA conditions are visible only under L (4 slots) and M (3 slots, conditional). The rim van der Pauw reads a meaningless mean | M3 potential at 295 K: holding x_in = 0.90 against x_exit = 0.652 over 15.6 µm needs **3.0 A cm⁻² absorbed**. At i = 300 mA cm⁻² and η = 0.5, x_in over F = **0.662** | Re-state P(cond_SRI) per slot. Put the L regime (with current modulation, which *is* SRI's no-through-flux geometry) on ≥2 quadrants per membrane. Add per-quadrant loading sensing (4-probe strips along each quadrant, or post-run XRD a-spacing). Match T-H per quadrant regime, not on the rim reading |
| **P3** | **Major** | Quadrant-to-quadrant misfit | Δx = 0.90 − 0.655 → Vegard strain 0.0652·Δx = **1.6 %**. Biaxial stress ≈ E/(1−ν)·ε/2 ≈ **1.6 GPa**, versus 40–150 MPa yield. Excess length gives ~0.4 mm wrinkles at λ ≈ 5 mm. Every P3 modulation cycles it | Model 2-D misfit in M3 (quadrant pattern plus Au-capped cross web). Pre-register AE event *positions* (≥2 AE sensors to localise) and exclude boundary-correlated events from H1a. Or group L-type and flux-type skins on different membranes |
| **P4** | **Major** | 15 µm breaks the ADR-004 ⁶LiF entry-face triton calibration, which was specified for 8–12 µm | 2.73 MeV t through 15.58 µm (loaded): **3 % of accepted tritons emerge**, median 0 MeV (≤0.16 MeV at normal incidence). At 12 µm unloaded they would emerge at 0.87 MeV | One calibration membrane per lot at 10 µm, or a locally thinned (≤10 µm) window with the ⁶LiF, measured by profilometry. Otherwise drop the claim that the tomography is calibrated through the real foil |
| **P5** | **Major** | Electrolyte-borne cosmic recoils are not in M5's budget and unbalance T1 (A − T-H) | Unshielded, PID window per cell: **n–p in the H₂O twin 0.036 /d** (peak window 0.013); D₂O n–d misID 0.006 /d; **D(n,np) breakup protons 0.008 /d**. Compare M5's total of 0.028 /d. The D-specific part is 0.014 /d (≈1.7 counts over 4 cells × 30 d); the H-specific part is 2.6× larger | Primary T1 background = the **same cell current-off and the D₂O/Pt twin** (both carry the D₂O recoils). T-H becomes secondary, with a modelled n–p term. Add these terms to M5 and fit them with the measured fast-n flux |
| **P6** | **Major** | Entry-face efficiency and tomography over the real acceptance | Accepted direction cosines: median 0.68, 10th percentile 0.37. Entry-face p: median **1.41 MeV** at the ΔE, which is the PID lower edge. ε_PID (δ source): 0.220 at the exit face, 0.203 mid-foil, **0.116 at the entry face**, 0.084 at the +2 µm tolerance. Energy does not map one-to-one to depth: z = 4 µm spans 2.34–2.76 MeV | Quote the reach per depth: entry face ≈ 2× worse (6×10⁻⁵–1.5×10⁻⁴ fusions/s). Measure each foil's thickness to ±0.3 µm. Pre-register a response-matrix unfold ε(z, E) instead of reading "energy = depth". An optional ≤30° honeycomb collimator on one quadrant gives real depth resolution |
| **P7** | **Major** | The regime claims for F and L depend on unmeasured surface kinetics | The F "clamp" holds only if gas exchange ≫ J. M3's bare-Pd lower bound (J_sat ≥ 1 mA cm⁻² at 25 °C) allows x_exit anywhere in [0.652, x_in]. L needs J ≈ 0: with 50 nm pinholes each drains ~3×10¹¹ D/s, so the Au cap must have ≤ 3×10⁴ pinholes/cm² to keep J < 1.6 mA cm⁻² | Run the P0b witness **at 0.5 bar D₂** (not vacuum) and include an L-type witness. Specify Au ≥ 50 nm and measure pinhole density (Cu-decoration or H-permeation witness) |
| P8 | Minor | Rn/Tn progeny and ¹⁰B markers land in the ΔE-only triton and ³He windows (secondary observables) | ²¹²Po α plated on the entry face: 0.7 % per decay in the t window (0.85–1.10 MeV) and 0.8 % in the ³He window (0.55–0.85). ²¹⁴Po: 1 % at the −2 µm tolerance. Sparging removes ²²²Rn, not ²²⁰Rn/²¹²Pb from Th in the salt or polymer. ¹⁰B marker ⁷Li (0.84 MeV) → ≈0.4–0.7 MeV at the ΔE (Li stopping estimated): 0.04–0.5 /d, and ×10³–10⁴ with the source boost | Remove the ¹⁰B dot from the telescope view during physics windows, or run the boost only in calibration blocks. Assay LiOD/D₂O for ²²⁸Th/²²⁶Ra. Treat the t/³He windows as non-primary unless they are backed by E-coincidence |
| P9 | Minor | D₂O tritium is unverified; M8 assumes T/D = 1.4×10⁻¹⁵ (≈150 Bq/kg) | Commercial D₂O at 10⁵–10⁷ Bq/kg gives ³He ingrowth of **10⁸–10¹⁰ /day** in 13 g. That compares with the ³He isotope-dilution spike (10⁹–10¹⁰ per aliquot) and dominates any H4 ³He test | Buy certified low-tritium D₂O. Assay every lot by LSC. Size the ³He spike ≥100× the ingrowth, or use ⁴He-pipette calibration |
| P10 | Minor | Internal numeric inconsistencies | x_exit(0.5 bar, 295 K): design 0.63, M3 **0.652**. P3 swing: 0.61↔0.67 in the design, M3 0.629↔0.670. ²¹⁴Po exit energy: design 1.26 MeV; recomputed 1.15 MeV (15 µm), 0.72 MeV (loaded 15.58 µm), 2.46 MeV (at −2 µm). Thickness 15 µm vs ADR-002 rev 2's 8–12 µm. §5's He-window rule (≤10 mA cm⁻²) vs P2, where F/X/ED permeate ~50–150 mA cm⁻²-equivalent | Fix the numbers. Use loaded thickness (×1.039) in all transport. State that the P2 He windows rely on the Pd–Ag path and not the M8 NEG sizing rule |
| P11 | Minor | Local (n,p)/(n,α) sources and blank-telescope blind spots | The Cu septum (≈6 cm² facing Si) and Mo grid give an (n,xp) estimate of ~0.01 /d in the PID window. Pd(n,xp) ~6×10⁻⁴ /d. The blank telescope (under 100 µm Al) sees none of the electrolyte, septum or grid terms. Muon-spallation neutrons from 5 cm Cu are not modelled | Add these to M5. Make one quadrant of B carry an identical septum. Measure fast-n inside the house |
| P12 | Minor | He release for X/ED is far below the quoted 0.85 | M8: a uniform source over δ gives f ≈ λ/δ. For ED (1 µm) with λ = 3–300 nm, **f = 0.003–0.3**. X (140 nm) is 0.02–1 | Quote floors per skin. Rely on quadrant melts for X/ED |

**Checked and negligible** (asked for explicitly):

| Candidate | Result |
|---|---|
| ⁶Li(n,t) tritons from 1 M LiOD reaching the telescope | 2.73 MeV t cannot cross 15.6 µm except from the first ~1 µm at normal incidence. Rate ≲10⁻⁹ s⁻¹, and PID rejects tritons anyway |
| ⁶Li(n,α)t ⁴He in the electrolyte | 5×10⁻⁴–5×10⁻³ /s (45–450 /d), against σ_B = 7×10⁵ /d |
| ¹⁰B marker ⁴He | ~1 /d (10³–10⁴ /d with the boost), ≪ σ_B |
| Radiogenic He in Pd, Au, Mo, Cu | < 10³ /d produced; not released at room temperature |
| n–d recoils in the 0.5 bar front gas | 2×10⁻⁴ /d |
| Energy loss in the D₂ gap | ≤ 6 keV for p. ε_PID changes < 2 % versus vacuum. The design's "gas is harmless for protons" holds |
| α misidentification | ²¹²Po α exits the foil at 3.1–3.4 MeV and stops in the 25 µm ΔE (limit 5.17 MeV), so PID rejects it (M5) |

## Details

### P1 — Polymer He paths (Critical)
- **Where the polymers are.** §3.2 specifies a PCTFE cell body with a 316L lid, and an FFKM "floating" seal between the electrolyte and the membrane rim. The front volume is all-metal, but its only barrier to the cell at the rim is that FFKM seal.
- **What M4 already says.** M4 §5.10 quantifies a single Viton O-ring at 0.8–1.8 mW-equivalent and allows PTFE only as a liner with no path to air.
- **Permeation estimate.** Take PCTFE He permeability as 1–30 Barrer. This is an order-of-magnitude range, but even 1 Barrer is ~100× Pyrex (Pyrex back-derived from M4 is ≈0.01 Barrer). Permeation then gives 10⁸–10⁹ He/s into the headspace, i.e. 0.4–4 mW-equivalent. §10's "0.4–1.6 nW" headspace/melt reach is wrong by ~10⁶ for the headspace part. The melt part is unaffected.
- **The front channel is not protected either.**
  - Any cell-side He inventory (10¹¹–10¹⁴ atoms from polymer outgassing, dissolved air, or incomplete sparging) sets a He partial pressure of 10⁻¹⁰–10⁻⁶ bar at the FFKM.
  - Crossover to the front is then 10⁴–10⁷ /s, versus the 43 /s floor.
  - The 1 % Kr tracer cannot detect this. Fluoroelastomer and fluoropolymer permeabilities for Kr are ≥10× lower than for He, so a clean Kr reading does not bound He.
- **The artifact is temperature-correlated.** Permeability rises by ~×2–3 per 20–30 K, so the P4 70–80 °C phase produces a **He rise that is correlated with temperature and therefore with current and heat**. That is the worst possible artifact for H2.
- **Fix (P1-fix).**
  - PTFE-lined 316L cell.
  - Membrane diffusion-bonded or brazed to a **non-hydriding annulus** (Pt, or Au-plated Cu, ~0.1 mm) that is then sealed with a Au-wire or CF knife-edge. The annulus does not load, so the rigid seal carries no misfit, which meets M3's "no rigid clamp on loading Pd" rule. Radial compliance comes from a thin corrugated annulus.

### P2 — Entry-face loading under the flux quadrants (Critical)
- **Result.** From `m3_common.Material(T = 295 K)`, x_eq(0.5 bar) = 0.652.
  - Φ(0.90) − Φ(0.652) over 15.58 µm gives J = 1.9×10²³ D m⁻² s⁻¹ (≈3 A cm⁻²). M6 §5 found ~1 A cm⁻² for 50 µm, so this is consistent.
  - The cell can absorb at most η·i ≈ 60–150 mA cm⁻².
  - Under a clamped exit the entry face therefore follows x_in = Φ⁻¹(Φ(x_exit) + ηiL) ≈ **0.655–0.662**.
- **The fallback in §15.1 is not what happens.** The design lists "M collapses into L or F" as an open risk. The stronger statement is that F, X and ED are *never* at SRI loading anywhere in the foil.
- **L-type slots reproduce SRI's geometry better than M.** SRI's cathodes are solid rods with in/out flux through one face and no through-flux. L plus the P3 current square wave is exactly that geometry at x ≥ 0.9 (given M2's x_in). L therefore deserves more slots.
- **Lateral coupling.** The first-eigenmode decay length is L/π to 2L/π = 5–10 µm, which confirms that quadrants are independent. It also means a single rim van der Pauw cannot report any quadrant's x.

### P3 — Misfit between quadrants (Major)
- **Magnitude.** L quadrants at 0.90 and F/X/ED at ~0.655 differ by Δx ≈ 0.245 → 1.6 % linear misfit (M3 η = 0.0652). Elastic accommodation would need ~1.6 GPa; annealed Pd yields at 40 MPa and 150 MPa after one transit.
- **Consequences:**
  - plastic flow and dislocation injection concentrated along the 1 mm Au cross web and quadrant edges;
  - out-of-plane wrinkling of the L quadrants (≈0.4 mm amplitude);
  - fatigue cracking under P3/P5 cycling.
- **Why it matters for H1.** Cracks at a skin boundary are the H1b confound, located exactly where the skin comparison is made. They are also leak paths for the cell→front seal.
- **Status of the model.** M3's mechanics are 1-D and uniform-x, so this is unmodelled.

### P4 — ⁶LiF positive control (Major)
- ADR-004 item 2 assumes an 8–12 µm membrane.
- At 15 µm (15.58 µm loaded) the 2.73 MeV t leaves the foil at 0.16–0.30 MeV only near normal incidence. Over the acceptance, 97 % of tritons stop or fall below the 0.1 MeV threshold.
- The foil-integrated depth calibration therefore does not exist for the as-designed membrane.

### P5 — Electrolyte recoils (Major)
- **Method.** MC of cosmic fast neutrons (M5 spectrum, 6.1×10⁻³ cm⁻² s⁻¹ above 1 MeV, unshielded) producing recoils uniformly in 2 mm of liquid above the Ø20 entry face. Recoils are transported through liquid → 15.58 µm PdD₀.₉ → gas, then through M5's `deposit` and `proton_cut`.
- **Cross-sections.** n–d elastic uses Gammel n–p, as in M5. Breakup σ(n,np) uses a threshold at 3.34 MeV, ~0.2 b at 10 MeV and 0.13–0.18 b above that (±50 %).
- **Size.** Multiply the table values by M5's shield factor 0.6 for the house. The H₂O twin's recoil protons (0.022 /d shielded) exceed M5's entire D-cell budget.
- **Consequences:**
  - The equal-time D − H test is biased negative, which weakens limits. The D₂O terms are D-specific and biased positive (≈1–2 counts over the 30-day, 4-cell sum, against a 5σ threshold of ~8).
  - Neither term is visible to the blank telescope.
  - The fix is to change the reference: current-off of the same cell and the D₂O/Pt twin both carry the same recoils.

### P6 — Acceptance smearing (Major)
- **Energy distributions.** See `figs/rt1a_tomography.png`.

  | Proton origin | E at ΔE, 10–90 % (MeV) |
  |---|---|
  | Exit face | 3.007–3.015 |
  | z = 4 µm | 2.34–2.76 |
  | Mid-foil | 1.56–2.51 |
  | Entry face | 0–1.93 (half below the 1.41 MeV PID edge) |

- **Consequences for §3.4:**
  - The table is the normal-incidence limit.
  - The entry-face ε is 0.116, not ~0.22. The M5 reach of 3–8×10⁻⁵ fusions/s applies only to the exit face.
  - ±2 µm thickness tolerance moves the entry-face ε between ≈0.15 and 0.084.

### P7 — Unverified regimes (Major)
- **F.** The clamp at x_eq assumes exchange ≫ J. M3 could not bound the room-temperature exit law to better than 10³–10⁴. If the bare-Pd exit is kinetics-limited near its 1 mA cm⁻² lower bound, F carries little flux and drifts toward L. P0b must therefore be run against 0.5 bar D₂ with a front-pressure-rise flux measurement per quadrant. Masking the other three quadrants is one way.
- **L.** Disk-sink flux per pinhole is 4aDnΔx ≈ 3×10¹¹ D/s (a = 50 nm, D = 10⁻⁶ cm² s⁻¹, Δx = 0.25). Typical 20 nm sputtered Au with 10⁴–10⁶ pinholes/cm² turns L into a 0.5–50 mA cm⁻² flux sector.

### P8–P12
See the table. The numbers come from §1b and §4 of `figs/rt1a_physics.txt`.

## Q6 — The single physics change that most raises P(detect) under ADR-003

**Make the cell and the membrane rim He-tight and polymer-free (P1-fix).**

Under ADR-003, H1 sensitivity is already saturated at ≤1 % of every claimed magnitude, so better silicon buys nothing. H2 carries 0.20 of the weight and is the only quantitative test of the SRI heat–⁴He claim. As designed, that channel's background (10⁸–10⁹ He/s, temperature-correlated) sits at or above 1 % of the SRI claim scaled to one L quadrant (≈2–5×10⁸ He/s after 0.6 release). Its credibility factor is also ≈0 because of the P4 warm-phase correlation.

The fix is cheap, costing only an all-metal cell and a bonded Pt annulus. It moves the headspace and front floors back to M8's 43–100 He/s, which is 10⁶× better.

Runner-up: re-allocate slots so that ≥2 of 4 quadrants per membrane are L-regime under current modulation (P2). That raises P(cond_SRI at a visible location) from 4/16 to ≥8/16 slots.

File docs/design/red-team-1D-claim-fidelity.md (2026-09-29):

# Red team 1D — Claim fidelity (proponent's brief against iteration-1)

**Reviewer stance:** the strongest well-informed LENR proponent (McKubre/SRI, Violante/ENEA, Iwamura, Kitamura/Takahashi, Clean Planet, Szpak/Mosier-Boss, Lipson, Czerski, Storms, Hagelstein). The job is to find every reason a null from `iteration-1.md` would be dismissed as out-of-regime.
**Date:** 2026-09-29 · **Inputs:** charter, ADR-002 rev 2, ADR-003, iteration-1, R1/R2/R7, M2, M3, M6, M8, red-team-0.
**Calculations:** new numbers were computed with `sim/m3_common.Material` (15 µm PdD, 25 °C) and the ADR-003 score formula; the commands are in the appendix. † marks literature values from memory that were not re-verified in this session.

---

## Summary verdict

The DFM-4 does not reproduce the SRI/ENEA regime over most of its entry face, and it cannot show that it does anywhere. The design's own drained-quadrant boundary condition (x_exit ≈ 0.63 on F/X, set by 0.5 bar D₂) combines with 15 µm of Pd to give a diffusion capacity of about 3.8 A cm⁻². That is more than 10× what the electrolysis can supply, so the whole column over F, X and ED, **entry face included**, sits at x ≈ 0.63–0.65 (computed below). Only L and M, 7 of 16 quadrant slots, can be at x ≥ 0.9. M reaches it only with a better surface than P2 will produce. L has no steady flux.

Loading is read by van der Pauw on an un-electrolysed rim that averages over all four regimes, so McKubre's criterion cannot be verified per sample. Every array membrane comes from one commercial, unscreened lot, so the design's "N = 4" is N_eff ≈ 1 for the dominant hidden variable. SRI and ENEA reported that variable directly: behaviour "varies very much with the lots", and lots without the favoured features gave nothing in either lab.

Add 22 °C, i ≤ 0.3 A cm⁻² (below SRI's i₀ = 0.4 for some cathodes), no Al/Si additive, no SuperWave, and a 3-week hold. A proponent would dismiss a DFM null on the SRI claim within one paragraph. The DFM's "Iwamura" and "Lipson" quadrants are not those experiments at all.

Under ADR-003's own scoring, the DFM as specified contributes about 0.4 of the programme's claim-score of about 2.3 while consuming about 75 % of the budget. C3-G (Iwamura) and a multi-cell C1 replica each score higher than the whole Tier-1 array. **Promote C3-G and a 4-cell, 2-lot C1 to Tier 1. Convert ≥ 2 DFM membranes to single-regime (L/M) faces. Screen lots before building.**

---

## 1. Claim-by-claim fidelity (as specified)

Fidelity is P(cond_c | d) in ADR-003, judged at a detector-visible location, 0–1.

| Claim (ADR-003) | Claimed conditions | Iteration-1 provides | Fidelity | Justification |
|---|---|---|---|---|
| **SRI/ENEA heat + ⁴He** (B−/C) | Bulk-average x ≥ 0.90 (best cells 0.95–1.0) by 4-wire R along the cathode. i above i₀ = 0.1–0.4 A cm⁻² (SRI ran to 0.5–1 A cm⁻²). Loading held "several weeks to a month" (R1 §3.1). Non-zero interfacial flux \|dx/dt\| from current steps. Closed Ø1 mm × 30 mm wire (SRI) or closed 50 µm foil (ENEA), vertical. **1.0 M LiOD at SRI**†, 0.1 M at ENEA/F-P. SRI Al/Si additions†. Temperature ≥ 30 °C typical. ENEA-processed or pre-screened lots (<100> texture, grains < 100 µm). The ICCF-14 ENEA/SRI lot replications ran SuperWave (see §5) | 15 µm permeating disk, horizontal, face up, 3.14 cm². 1.0 M LiOD. 200–300 mA cm⁻². 22 °C. One commercial lot, unscreened. No additive. P2 ≥ 3 wk. Current square wave with **anodic** −100 mA cm⁻² half-cycles. Loading read on the rim | **DFM 0.20** (L/M only). **C1 twin 0.40** | Only 7/16 of the entry area can be in regime (§2). x_in ≈ 0.915–0.924 with a "good" surface (M2 §5.1), so the (x−x₀)² factor is 5–25× below SRI's best cells. Below i₀ for x₀ = 0.832/i₀ = 0.4 cathodes. Lot risk is uncontrolled. C1 is closer in geometry but runs at 0.1 M (the F-P/ENEA lineage, not SRI's), N = 1, with no lot control |
| **Iwamura Pd/CaO permeation transmutation** (B, contested) | D₂ gas 1 atm upstream, vacuum downstream, ~70 °C, Pd 25×25×0.1 mm substrate, multilayer + Cs/Sr on the **entry** face, J = 3–7×10¹⁷ D cm⁻² s⁻¹, ~1–2 weeks per sample. MHI substrate prep (anneal, etch†). Cs→Pr is the channel Toyota replicated by ICP-MS (JJAP 2013), Sr→Mo the secondary | **DFM X:** multilayer on the exit face, electrolytic entry, 22 °C, 0.5 bar D₂ downstream, no target element. **C3-G:** 100 µm Pd, 1 atm D₂, 70 °C, multilayer + ⁸⁶Sr on the entry face, J target matches; H₂, no-CaO and static controls; N and Cs not specified | **DFM X 0.03. C3-G 0.60** | The DFM X quadrant reverses the geometry, has no transmuting target, and runs at the wrong temperature, phase and gas side: it is not the Iwamura experiment, yet §1/§10 claim an "Iwamura interface" limit from it. C3-G is close, but drops the replicated Cs→Pr channel for a novel ⁸⁶Sr tag that the claimants never ran |
| **Kitamura/Takahashi CNZ/PNZ** (B in-network) | 100–200 g of claimant-type (Santoku/Technova-lineage†) Pd–Ni or Cu–Ni/ZrO₂, calcined/baked pretreatment, H₂ or D₂ at 0.1–1 MPa, 200–300 °C (up to 450), weeks, oil-flow calorimetry | Tier 3 outline, 100 g, 200–300 °C, flow jacket, inert twin | **0.35** | Right regime, but powder provenance and pretreatment are unspecified, and N = 1 charge. Heat also claimed in H₂, which the ⁴He accounting cannot test |
| **Tohoku / Clean Planet Ni/Cu** (C) | 6×[Cu 2 / Ni 14 nm] on 25×25×0.1 mm Ni, H₂ loaded ~250–270 °C for ~16 h, evacuated, heated to 500–900 °C, repeated cycles, days–weeks | Tier 3 outline, as claimed | **0.50** | Faithful on paper. Radiometric calorimetry is emissivity-limited (R2); sample count unstated |
| **SPAWAR co-deposition** (C/D) | PdCl₂ + LiCl in D₂O on Au/Ag, stepped current, CR-39 in contact, days | Tier 3 PSD-scintillator arm, open cell | **0.60** | Chemistry is faithful. The detector is not CR-39, so a null can be argued away by "the PSD threshold misses the pits' low-energy/heavy component" |
| **Lipson Pd/PdO:D desorption** (C/D) | Au/Pd/PdO heterostructure, electrolytic loading, then **controlled exothermic desorption** facing Si/CR-39; 3 MeV p, 11–20 MeV α claimed | F quadrant: bare Pd exit in 0.5 bar D₂ during electrolysis. PdO and the Au/Pd/PdO skin are rejected (M3, M6). No desorption window | **0.10** | Wrong surface, wrong phase (loading, not desorption), and exit gas instead of vacuum |
| **Czerski beam-free 511 keV** (D) | D-loaded Pd/Zr, no beam, very low (underground) background, 511–511 coincidences (ICCF-26) | LaBr₃ pair at a surface lab, Cu shield, muon veto | **0.30** | Conditions are loose; background is the fidelity issue. M7 is still pending |
| **NTT out-diffusion bursts** (D) | Pd with Au on one face, oxide on the other, gas-loaded, then out-diffusion into **vacuum** | L quadrant Au cap; front at 0.5 bar D₂; no evacuation step | **0.10** | No out-diffusion into vacuum is ever performed |

---

## 2. Is McKubre's criterion met, quadrant by quadrant?

McKubre's criterion has four parts: (i) x ≥ 0.9 bulk-average, (ii) i > i₀, (iii) t ≥ 10 τ_D (in practice weeks), (iv) non-zero flux.

**The 15 µm column follows its exit boundary condition.** The steady flux through 15 µm PdD at 25 °C comes from Φ(x_in) − Φ(x_exit) (`sim/m3_common.Material`):

| x_in → x_exit | J (mA cm⁻² equivalent) |
|---|---|
| 0.92 → 0.63 (design's stated F/X exit) | **3 940** |
| 0.95 → 0.63 | 4 096 |
| 0.92 → 0.90 | 137 |
| 0.95 → 0.90 | 293 |

The cell passes at most 200–300 mA cm⁻² in total, and only part of that is absorbed. Solving for x_in over a quadrant whose exit sits at 0.63 gives:

| Absorbed flux (mA cm⁻²) | 10 | 50 | 150 | 300 |
|---|---|---|---|---|
| x_in | 0.631 | 0.633 | 0.638 | **0.646** |

Lateral coupling is about one membrane thickness (red-team-0 §3.1), so the entry face above F, X and ED sits at **x ≈ 0.64**. That is β-phase minimum, far below x₀. The design says the telescope sees "the electrolyte-facing surface where the classic high-loading claims were made". That holds only over L and M.

| Quadrant | x_entry | x_exit | Steady J | (i) x ≥ 0.9 | (ii) i > i₀ | (iv) flux | Verdict |
|---|---|---|---|---|---|---|---|
| **L** (Au cap) | 0.915–0.924 (good surface, 200–300 mA cm⁻², M2) | same | ≈ 0 | yes, marginal | marginal (≤ 0.3 A cm⁻²) | only during current steps | **Closest SRI analogue** (a closed cathode with transient dx/dt). It is not called that, and P3's anodic half-cycles deload it |
| **M** (Ni 2–20 nm) | needs ≥ 0.95 per M3, but only 0.92 is reachable | ~0.915 with 20 nm Ni at x_in 0.92 (the 0.92→0.90 capacity is 137 mA cm⁻², so J ≈ 10 mA cm⁻² barely tilts the column) | ~10 mA cm⁻² | marginal | marginal | steady through-flux | Can hold x ≈ 0.91–0.92 *with* flux if Ni is ≥ 20 nm. Contrary to §15 risk 1, M does not collapse at x_in = 0.92; it runs at a lower (x − x₀)². Proponents will argue that steady through-flux is not SRI's \|dx/dt\| |
| **F** (bare) | **0.64** | 0.63 (design) | supply-limited | **no** | — | yes | Out of the SRI regime. If M3's saturation-cap branch holds instead, F is loaded but has ~1 mA cm⁻² flux, and the design's F label is wrong. Either way it is not the claimed state |
| **X** (CaO ML) | **0.64** | 0.63 | supply-limited | **no** | — | yes | Out of regime for SRI. For Iwamura it is the wrong face, temperature and gas |
| **ED** (1 µm e-dep Pd) | **0.64** (behaves like F) | ≈ 0.63 | supply-limited | **no** | — | yes | Out of regime |

- **Criterion (iii)** is trivially met in charge: 10⁷ C per mol Pd (Cravens–Letts) is 5.3 kC for a 4.7 mm³ membrane, about 2 h at 0.8 A. It is not met in calendar time. P2 is 3 weeks, while McKubre gives "several weeks to a month" and F-P runs went to months. R1 §3.2 notes that the incubation is not diffusion-limited, so thinness buys nothing.
- **The loading gauge is invalid.** The van der Pauw contacts sit on the Ø26 rim, outside the Ø20 wetted area and under the seal. The rim loads only laterally, so it averages over the L/M/F/X column states. R/R₀ is double-valued, and the rim mixes a 0.92 region with 0.64 regions. The measured "mean x" therefore does not test any quadrant against x ≥ 0.9. **A proponent will say, correctly, that the design never demonstrated the loading at the location where it reports a null.**
- **M2/M3 numbers, critically.** The "good" surface class (x = 0.90 at 86 mA cm⁻²) is fitted to ENEA-type *vacuum-annealed + etched* samples (M2 §4). It is calibration, not prediction. A single commercial lot, anodised by P3 half-cycles and exposed to Pt redeposition from a mesh 4 mm above a horizontal face-up disk, will more likely behave as "typical" (x ≈ 0.87 at 300 mA cm⁻², M2 §5.1). In that case **no quadrant reaches 0.9.** The only quantitative lever M2 offers is a recombination poison (P = 10 → +0.065). The design omits it.

---
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

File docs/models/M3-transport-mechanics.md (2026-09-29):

# M3 — Deuterium transport, permeation, phase transition and mechanics

Code: [`sim/m3_common.py`](../../sim/m3_common.py) (physics + solver), [`m3_loading.py`](../../sim/m3_loading.py), [`m3_membrane.py`](../../sim/m3_membrane.py), [`m3_mechanics.py`](../../sim/m3_mechanics.py), [`m3_cycling.py`](../../sim/m3_cycling.py), [`m3_sensitivity.py`](../../sim/m3_sensitivity.py). `python3 sim/m3_run_all.py` regenerates everything (≈25 min on 1 CPU). Raw outputs: `figs/m3_*.txt`.

## Summary for lead

1. **Transport is not the bottleneck.** With the α/β moving boundary included, PdD reaches 0.9·x_s in 4.4 s (25 µm film), 70 s (100 µm) and 50 min (1 mm-radius wire). Charging efficiency and surface kinetics (M2) set real loading times.
2. **DFM flux budget:** J·L ≤ Φ(x_in) − Φ(0.90). For x_in = 0.95 and L = 25 µm this is 1.1×10²² D m⁻² s⁻¹ (176 mA cm⁻²). **If M2 cannot reach x_in > 0.90, no exit finish keeps the exit ≥ 0.90 with any flux.**
3. **Exit face decides everything.** The required k_r is 3×10⁻⁴⁰ to 1×10⁻³⁷ m⁴ s⁻¹, which is 10³–10⁴× below literature Pd unless surface saturation caps desorption. Iwamura's data only bound that cap from below. **Measure the bare-Pd exit law on a witness membrane first.** Reject PdO (reduced in seconds) and continuous Au/Cu/Ni-Cu (zero flux). Pd/CaO shows no barrier function. Use Ni 2–20 nm or a patterned Au mask to tune.
4. **Mechanics:** 25 ± 5 µm annealed Pd, floating seal, on a vacuum-side Mo grid with 1.0 mm holes and 0.15 mm webs (27 MPa at 1 atm, open fraction 0.69). Clamped rims fail: loading is ~10⁴× the buckling strain. Unsupported discs see 600–1000 MPa.
5. **Protocol A:** one slow α→β transit, then hold. It stays elastic (6 MPa), and with a barrier exit a current loss takes months to re-form α.
6. **Protocol B1** (β-phase flux pumping) is damage-free.
7. **Protocol B2** (α/β cycling, 33 min period): 7 % plastic strain per cycle and 0.01–0.6 cm² of new crack face per cm² per cycle, with a through-crack after ~10–180 cycles. **Cap B2 at ≤ 10 cycles with a leak interlock.**
8. **Room-temperature electrolysis cannot create Fukai superabundant vacancies:** vacancies move less than 1 nm per day at 25 °C.

---

## 1. Questions answered

| # | Question (brief) | Where |
|---|---|---|
| Q1 | Loading time vs dimension (wire, foil, film, nanoparticle) with α/β miscibility gap and moving boundary | §5.1, Table 5.1, `m3_loading_time.png` |
| Q2 | DFM steady/transient profiles, flux, exit-face loading vs thickness (5–200 µm) and k_r; comparison of PdO, Au, CaO/Pd, Ni/Cu, clean Pd | §5.2, `m3_dfm_chart.png`, Table 5.4 |
| Q3 | When loading/deloading/gradients crack or buckle the membrane/film; pressure differential; clamping | §5.3 |
| Q4 | Two protocols: (a) crack-free high loading, (b) deliberate α/β cycling (crack area per cycle, vacancies, SAV) | §5.4 |
| Q5 | Temperature (20–90 °C) and isotope (H control) | §5.5 |

## 2. Model and equations

**Thermodynamics.** The chemical potential per absorbed atom is μ/kT = ½ ln(f/1 bar), where f is the equilibrium fugacity. The isotherm is piecewise, with a Maxwell construction:

- **α branch (x < α_max):** ideal Sieverts, ½ln(f/f_pl) = ln[x/(1−x)] − ln[α/(1−α)].
- **Two-phase region:** flat, f = f_pl(T). Plateau from van 't Hoff, ln f_pl = ΔH/RT − ΔS/R.
- **β branch (x > β_min):** ½ln(f/f_pl) = k_β(T)(x−β_min) − g ln[(1−x)/(1−β_min)], with k_β ∝ 1/T (enthalpic interaction) and g = 0.1.
- **Calibration of k_β:** k_β = 19.1 at 298 K so that PdD has f(0.90) = 10⁴ atm. This then predicts f(0.95) = 7.8×10⁴ atm (consistent with x = 0.95 at 0.92 GPa of D₂), x(1 bar) = 0.666 for D and 0.698 for H (literature ≈ 0.67 and 0.70).
- **Gap boundaries vs T:** α_max(T) and β_min(T) scale as (1 − T/T_c)^0.40 around x_c = 0.27, anchored to 0.017/0.59 for H at 25 °C. D uses its own T_c by corresponding states.

**Transport.** The tracer diffusivity is D* = D_α(T)(1−x), with the (1−x) factor for site blocking. The chemical (Fick) diffusivity is D_chem = D* · x · d(μ/kT)/dx [m² s⁻¹]. Its limits:

- α phase: D_chem = D_α exactly.
- Gap: D_chem = 0.
- β phase: D_chem = D_α(1−x)x(k_β + g/(1−x)), which is 2.3×10⁻¹⁰ m² s⁻¹ at x = 0.7 and 1.0×10⁻¹⁰ at x = 0.9 (PdD, 25 °C).

The Kirchhoff potential Φ(x) = n_Pd ∫₀ˣ D_chem dx′ [m⁻¹ s⁻¹] makes the flux exact: **J = −∂Φ/∂z**. The conservation law n ∂x/∂t = −r⁻ᵏ∂_r(rᵏJ), with k = 0, 1, 2 for slab, cylinder and sphere, is then a degenerate (Stefan-type) problem. The flat part of Φ in the gap produces a sharp α/β front automatically (an enthalpy method).

**Solver.** 1-D finite volume on geometrically graded grids, backward Euler, and Newton with residual backtracking. Φ is the exact integral of a piecewise-linear D_chem table, which keeps the Jacobian consistent.

**Steady DFM.** The profile is exact: J = [Φ(x_in) − Φ(x_exit)]/L = J_out(x_exit), solved with brentq, and x(z) = Φ⁻¹(Φ(x_in) − Jz).
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

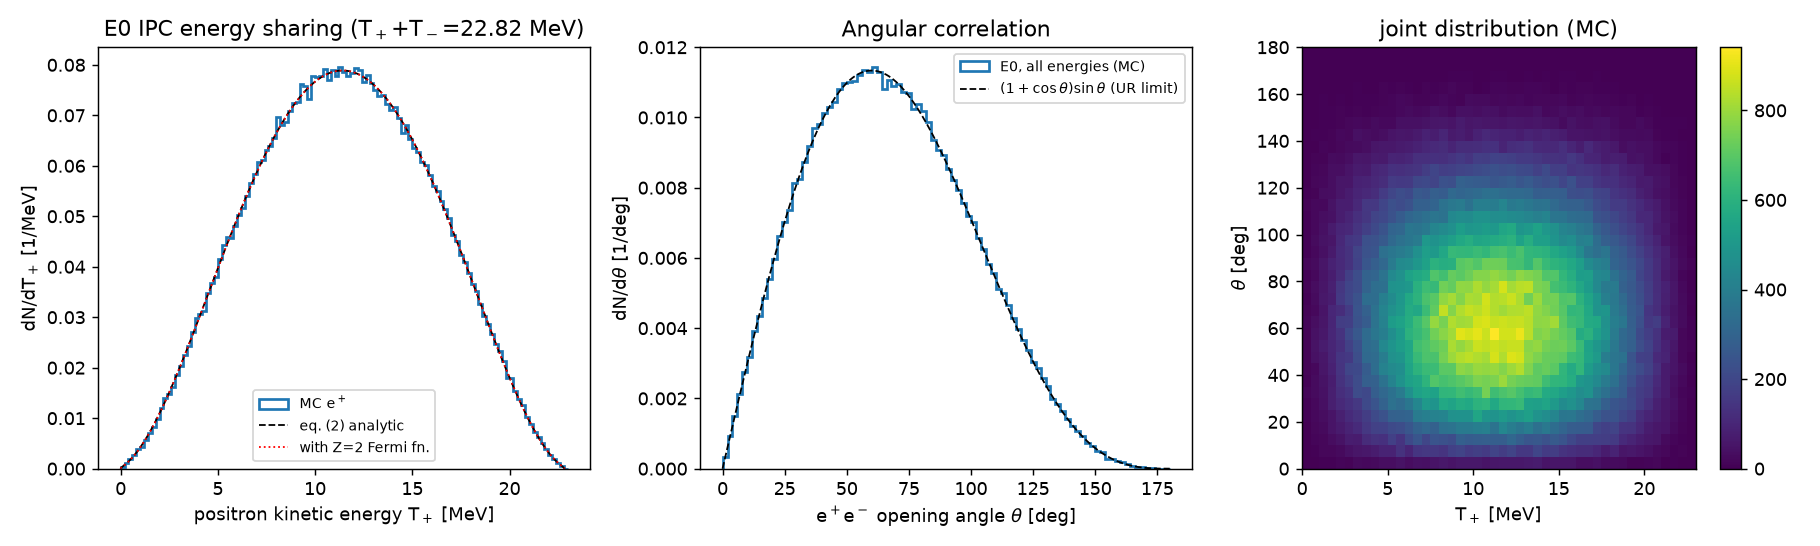
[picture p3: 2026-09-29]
docs/models/figs/m7_ipc_kinematics.png

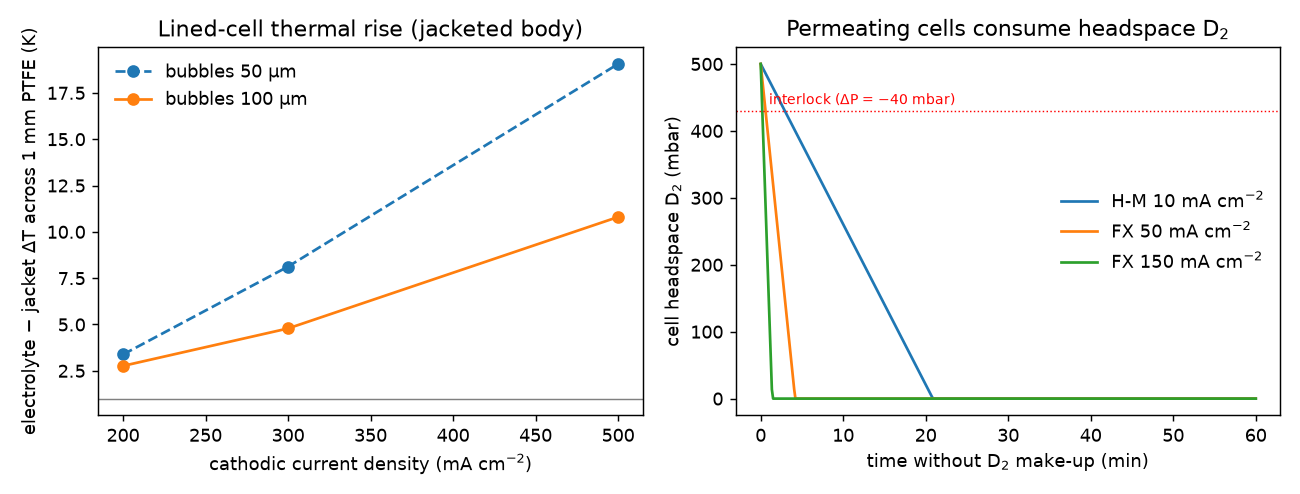
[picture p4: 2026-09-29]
docs/design/figs/rt1b_checks.png

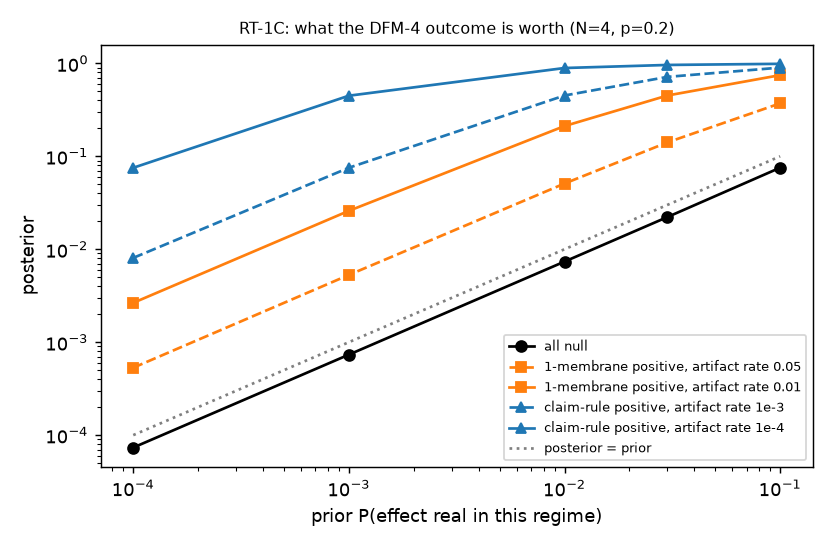
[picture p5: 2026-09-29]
docs/design/figs/rt1c_posterior.png

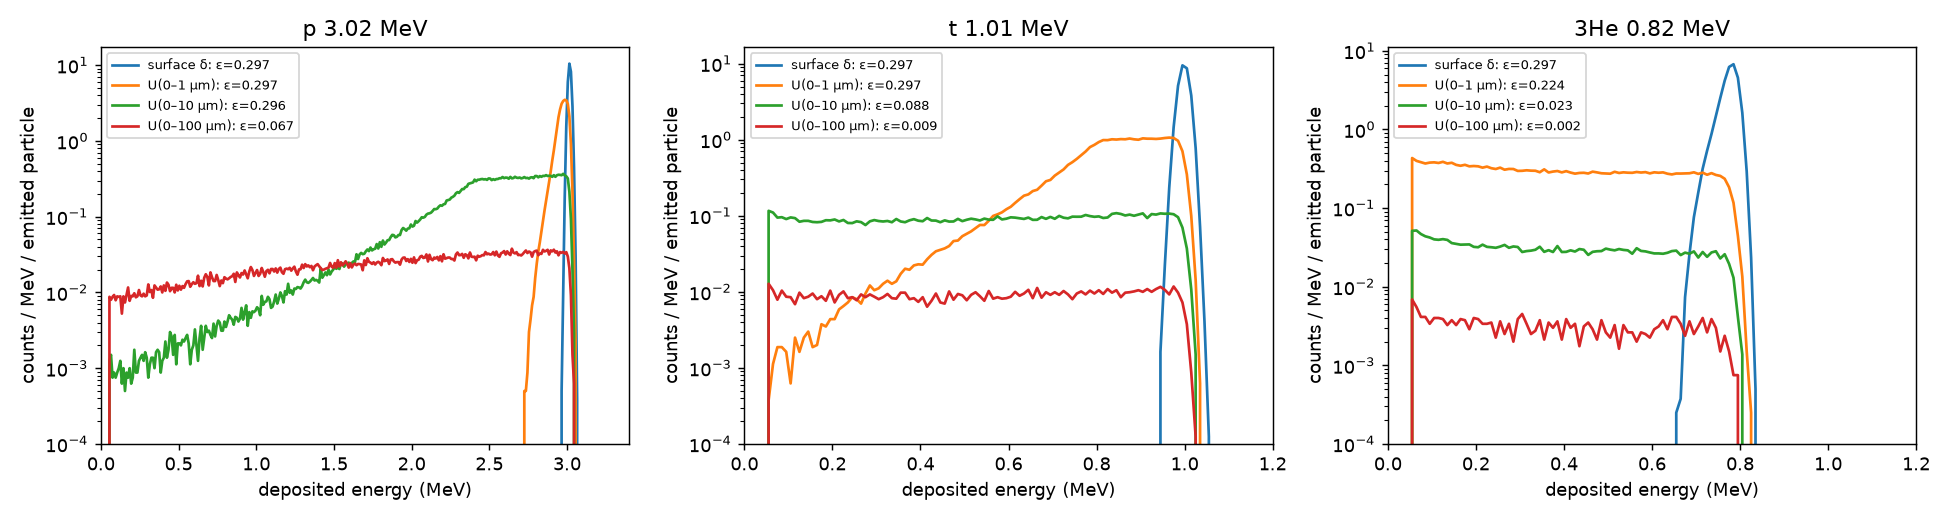
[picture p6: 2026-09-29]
docs/models/figs/m5_escape_spectra.png

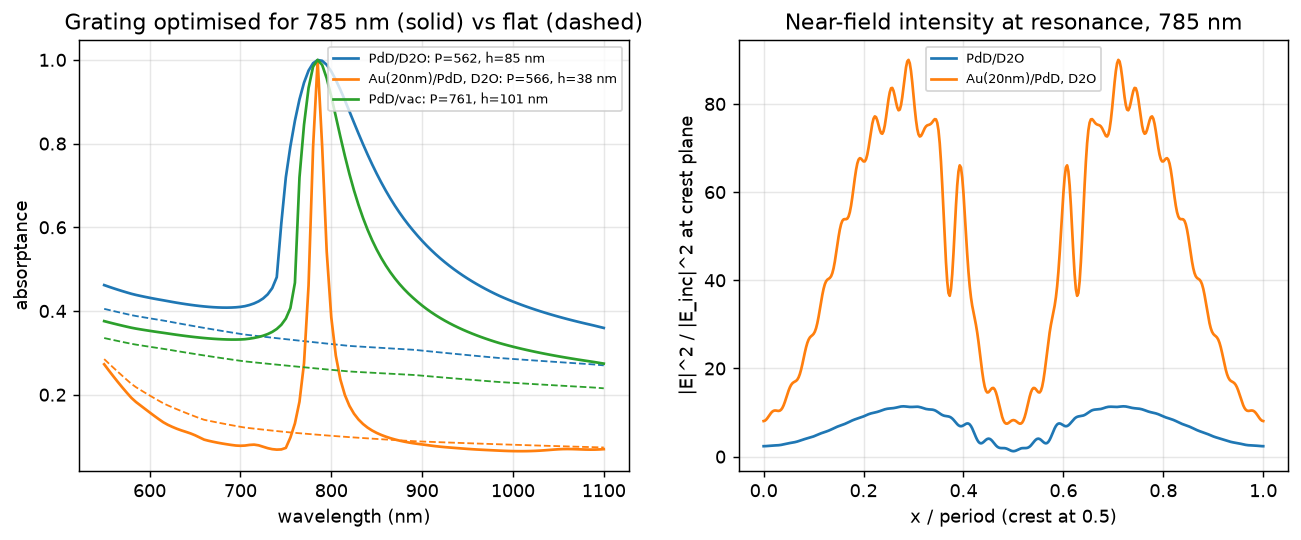
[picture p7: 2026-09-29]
docs/models/figs/m6_grating_spectra.png

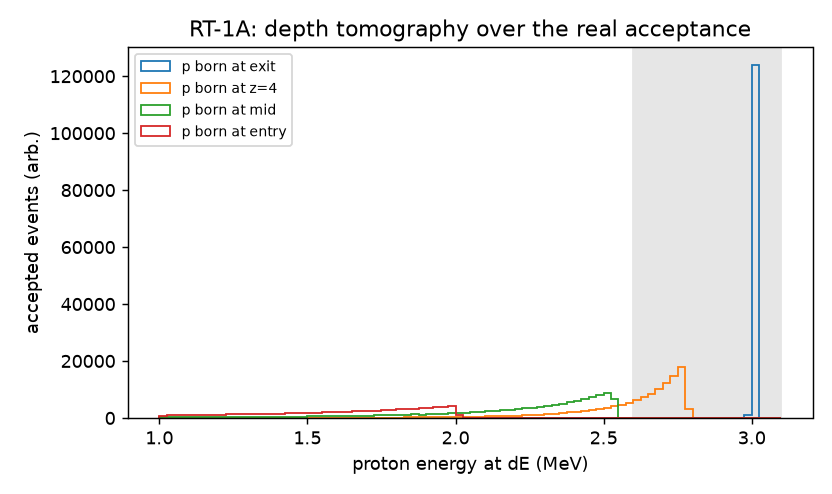
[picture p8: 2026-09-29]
docs/design/figs/rt1a_tomography.png

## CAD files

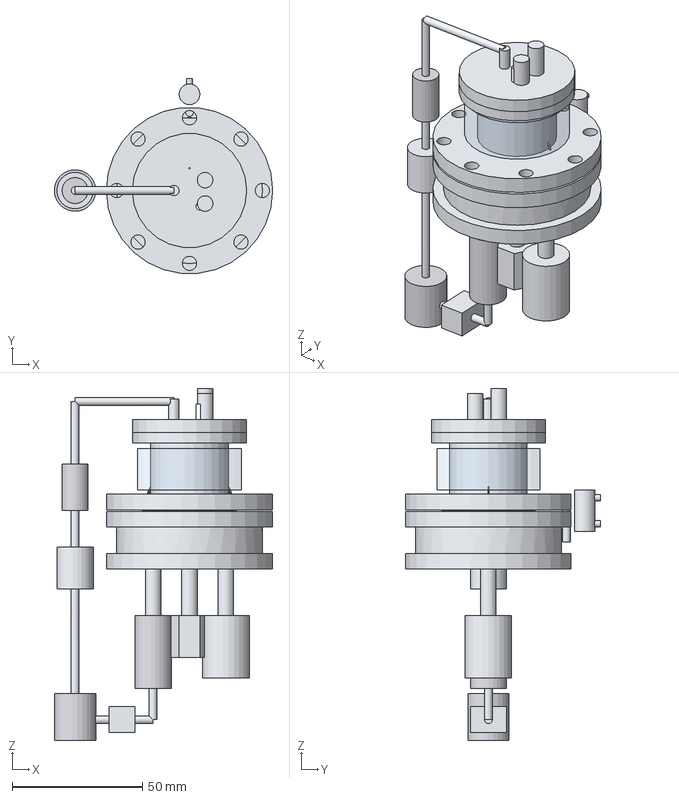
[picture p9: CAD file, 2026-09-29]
docs/design/cad/dfm_cell.step
84.0 x 74.8 x 135.3 mm
cell_body_316L
PTFE_liner
lid_316L
electrolyte_LiOD_D2O
Pt_mesh_anode
anode_feedthrough
recombiner
aux_Pt_cathode_ring
RTD_thermowell
water_jacket
forward_relief_valve
Pd_membrane_12um
exit_finish_Au50nm
Pt_corrugated_annulus
Au_wire_seal_upper
Au_wire_seal_lower
Mo_catch_grid
cross_septum
Si_dE_25um_quadrants
dE_alumina_board
Si_E_500um
E_alumina_board
front_volume_316L
front_ports
PdAg_element_350C
all_metal_valve_He_manifold
capacitance_gauge
reverse_relief_line
recycle_line
mass_flow_meter_flux_regressor
metal_bellows_pump
recycle_return_line
PdAg_return_element
buffer_volume

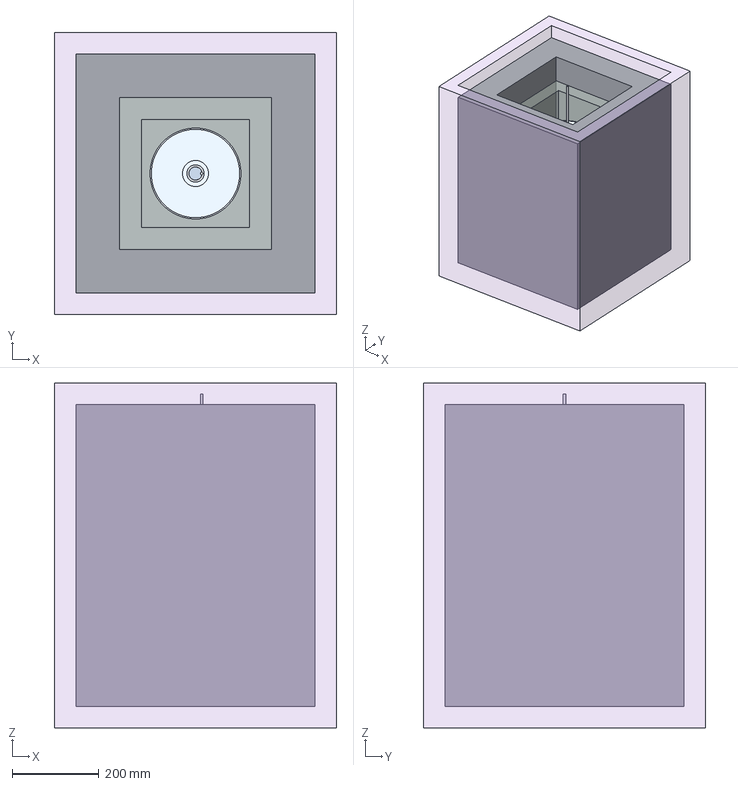
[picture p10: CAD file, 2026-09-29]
docs/design/cad/gamma_station.step
649.2 x 649.2 x 793.2 mm
NaI_well_8x8in
NaI_Al_can
PMT_3in
mini_permeation_cell
mini_cell_electrolyte
mini_cell_Pd_foil_12um
mini_cell_services_UHV_RGA
borated_HDPE_5cm
Pb_shield_10cm
veto_5cm_5faces

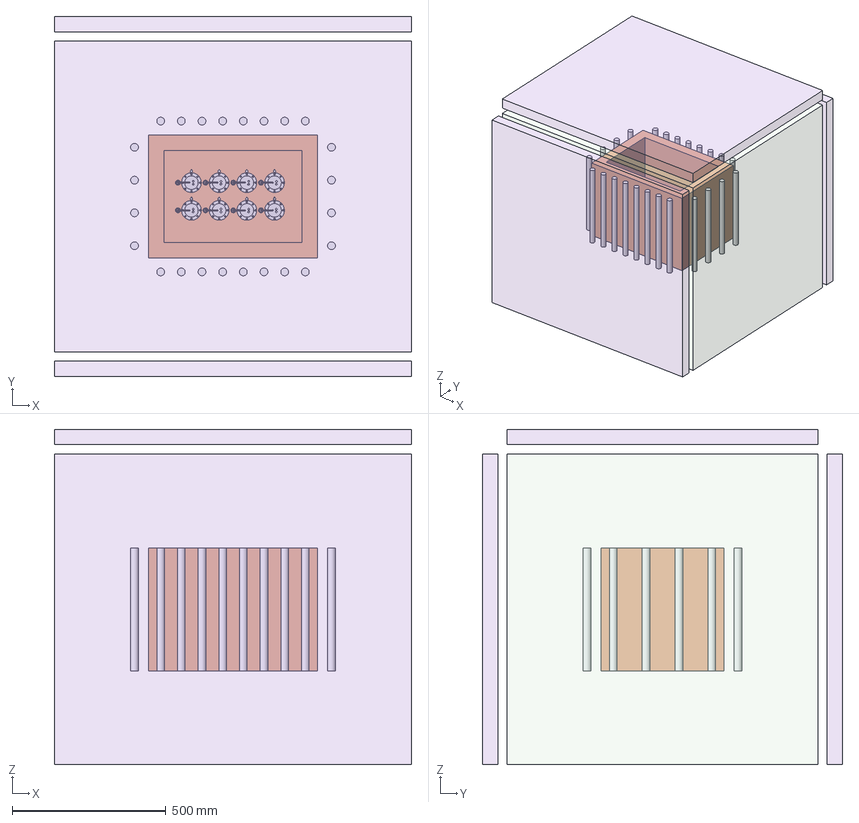
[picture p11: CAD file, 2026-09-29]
docs/design/cad/dfm_house.step
1160.0 x 1170.0 x 1090.0 mm
Cu_inner_shield_5cm
HDPE_moderator_3He_bank
borated_HDPE_20cm_plus_Cd
He3_tubes_24x
muon_veto_top
muon_veto_side_S
muon_veto_side_N
cell_body_316L x 8
PTFE_liner x 8
lid_316L x 8
electrolyte_LiOD_D2O x 8
Pt_mesh_anode x 8
anode_feedthrough x 8
recombiner x 8
aux_Pt_cathode_ring x 8
RTD_thermowell x 8
water_jacket x 8
forward_relief_valve x 8
Pd_membrane_12um x 8
exit_finish_Au50nm x 8
Pt_corrugated_annulus x 8
Au_wire_seal_upper x 8
Au_wire_seal_lower x 8
Mo_catch_grid x 8
cross_septum x 8
Si_dE_25um_quadrants x 8
dE_alumina_board x 8
Si_E_500um x 8
E_alumina_board x 8
front_volume_316L x 8
front_ports x 8
PdAg_element_350C x 8
all_metal_valve_He_manifold x 8
capacitance_gauge x 8
reverse_relief_line x 8
recycle_line x 8
mass_flow_meter_flux_regressor x 8
metal_bellows_pump x 8
recycle_return_line x 8
PdAg_return_element x 8
buffer_volume x 8
chilled_water_loop

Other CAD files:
docs/design/cad/dfm_cell.stl

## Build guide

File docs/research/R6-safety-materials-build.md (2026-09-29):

# R6 — Safety, Materials, Sourcing, Costs, and Build Constraints

*Research date: 2026-09-29. Scope: the practical and safety envelope that any LENR (Pd/D electrolysis, co-deposition, or gas-loading) geometry must fit inside.*

> **Source-quality note.** Web page fetching was blocked in this research session, and most vendor catalogs (Fisher, Sigma, Goodfellow) put prices behind a login. Items marked **(sourced)** come from a cited page or search-indexed snippet. Items marked **(est.)** are engineering estimates from metal spot value plus typical fabrication and catalog markups. Get quotes before committing money. The hazard calculations are first-principles and are shown in the text so they can be checked.

---

## 1. Executive summary

- **The main hazard is chemical: D₂/O₂ in the headspace.** It is not radiation. Every documented LENR accident was a gas-phase explosion or a stored-energy release: SRI 1992 (one death), the Fleischmann–Pons cube in 1985, Biberian 2004, and Mizuno 2005. One litre of stoichiometric 2D₂+O₂ at 1 bar holds about **6.7 kJ, roughly 1.6 g TNT-equivalent**.
- **Keep the headspace small and never let it become stoichiometric.** In open cells, sweep with an inert gas at **≥0.8 L/min per amp** (holds D₂ ≤1%, i.e. 25% of the LFL). Closed cells should be D₂-prefilled, fitted with a recombiner, and **tripped when ΔP ≥ 10% of the absolute fill pressure**, which keeps O₂ ≤3%, below the ~5% limiting oxygen concentration.
- **Closed-cell pressure rating:** if a detonable mixture cannot be ruled out, the design must survive about **20× the initial absolute pressure** (Chapman–Jouguet), or about 50× where reflected detonation is possible. Otherwise prevent the mixture by design and fit a burst disk.
- **Oxygen-clean everything.** The SRI forensic analysis (LLNL) found hydrocarbon machining oil inside the metal cell, in an O₂-enriched headspace. Use no organics except fluoropolymers.
- **Limit the stored-energy inventory.** Pd loaded to D/Pd ≈ 0.9 holds about **12–15 kJ of combustible D per cm³**. Keep cathodes **≤0.3 cm³**, avoid sealed hollow cathodes, and deload before opening a cell.
- **Keep the electrical system SELV:** ≤60 V DC at maximum current. This limits the electrode gap to roughly ≤5 mm for a plate at 1 A/cm² in 0.1 M LiOD.
- **Palladium is cheap; detectors and calorimetry are not.** Pd spot is **$1,198–1,265/ozt ($38.5–40.7/g)** (Sept 2026), so a 1 mm × 10 cm wire holds about $36 of metal. D₂O costs about **$0.3–0.65/g** in bulk and $1–3/g at retail (est.).
- **Add a neutron monitor with automatic shutdown.** A hypothetical 1 W of textbook D–D fusion would give about 9 Sv/h at 1 m. It has never been observed, but the alarm is cheap and the monitor doubles as the signal detector.
- **Regulatory load is light** with no licensed sources, no accelerator or X-ray generator, and tritium below the 1,000 µCi exempt quantity. D₂O needs no US purchase license; exports fall under 10 CFR 110.
- **Recommended tier: about $50k.** It buys Seebeck calorimetry (±20–60 mW), a closed-cell safety system, He-3, NaI and CR-39 detection, a vacuum anneal furnace, and outsourced SEM. $5k cannot produce credible calorimetry. Most of the $500k tier goes to staff, parallel cells, and ⁴He mass spectrometry.

---

## 2. Incident record and lessons

| Incident | What happened | Cause | Lesson for the geometry |
|---|---|---|---|
| **SRI International, 2 Jan 1992** (Andrew Riley killed, three injured) | Riley lifted the metal cell out of its water bath and was waiting for it to drain when it exploded. | D₂ + O₂ had accumulated **despite an internal recombiner**. LLNL forensics found **hydrocarbon (machining) oil** inside the cell and no explosives. Oil plus an O₂-enriched headspace can react explosively. | Oxygen-clean all parts. Trend pressure to catch recombiner failure. **Never handle, tilt or open a cell until it is deloaded and purged.** |
| **Fleischmann & Pons, Feb 1985** | A 1 cm Pd cube reportedly melted and partly vaporised, destroying the bench and pitting the concrete floor about 4 in deep. | Disputed. F&P offered an ignition interpretation and urged "extreme caution". | Keep Pd volume small and fit a thermal cutoff for unattended runs. Loaded Pd is a **fuel store**. |
| **Biberian, 2004** (glass tube, hollow Pd cathode) | The glass tube was shattered into many small pieces. The electrodes were unaffected. | Gas-phase explosion, probably initiated by **SWACER** from a reaction in the hollow cathode (Ruer & Biberian, JCMNS 26, 2018). | **No hollow cathodes.** Glass cells need secondary containment. |
| **Mizuno, 2005** (plasma electrolysis, glass cell) | Electrolyte went from 25 to 70 °C in about 10 s, then the cell exploded. Mizuno, about 1 m away, was cut by glass and deafened for a week. | H₂/O₂ in the headspace suspected. Not established. | High-voltage plasma electrolysis needs remote operation and a blast enclosure. |

A SPAWAR co-deposition cell also had a "catastrophic thermal event" after 3 days. Co-deposition cells need the same thermal cutoffs and enclosures.

---

## 3. Key hazard physics (design numbers)

**Faradaic gas generation** (D₂O, 25 °C, 1 bar), per amp of cell current:

- D₂: 5.18 µmol/s, or **7.6 mL/min**
- O₂: 2.59 µmol/s, or 3.8 mL/min
- Total: **11.4 mL/min (0.68 L/h)**
- D₂O consumed in an open cell: **9.0 g per amp-day**. A 60-day run at 1 A uses about 540 g.
- Recombination heat inside a closed cell: **1.53 W per amp** (thermoneutral voltage of D₂O ≈ 1.527 V)

**Flammability.** H₂ in air: LFL 4%, UFL 75%, detonable 18.3–59%, minimum ignition energy **0.017 mJ**, autoignition about 585 °C. H₂ in O₂: about 4–94%. Payman & Titman (Nature, 1936) measured D₂ limits in air and O₂ and found them similar. **Treat D₂ as H₂ for design.** The limiting O₂ concentration is about 5%, so a D₂-rich atmosphere is non-flammable only while O₂ stays ≤5%. Industrial recombiners start working at 0.2–4.4% H₂, depending on temperature, pressure and steam.

**Headspace energy** (stoichiometric 2D₂+O₂, 1 bar, reacting to D₂O vapour, 249 kJ/mol):

| Headspace volume | 10 mL | 50 mL | 100 mL | 500 mL |
|---|---|---|---|---|
| Energy | 67 J | 0.34 kJ | 0.67 kJ | 3.4 kJ |
| TNT-equivalent | 0.016 g | 0.08 g | 0.16 g | 0.8 g |

**Pressure rise from ignition in a closed vessel:**

- Adiabatic isochoric complete combustion: about **8–10× P₀**
- Chapman–Jouguet detonation of stoichiometric H₂/O₂: about **18–19× P₀**
- Reflected detonation: about **45–50× P₀**

**Closed cell with a failed recombiner:** dP/dt = 0.23 bar/min per amp in 50 mL of headspace (it scales as I/V). If the cell starts O₂-free at absolute pressure P_fill, the O₂ mole fraction after a fractional pressure rise r = ΔP/P_fill is x_O₂ = r / 3(1+r). **Keeping x_O₂ ≤3% requires r ≤ 0.10**, whatever the volume or current. Example: 2 bar D₂ fill, 50 mL, 1 A. The trip at ΔP = 0.2 bar is reached in about 105 s, with O₂ at 3%. Without a trip, O₂ reaches 5% in about 3 min.

**Stored chemical energy in loaded Pd:** 1 cm³ of Pd holds 0.113 mol Pd. At D/Pd = 0.9 that is 0.051 mol D₂, or **12.7–15 kJ/cm³** if burned. A 1 mm × 2 cm wire (0.016 cm³) holds about 0.2 kJ. The F&P 1 cm cube held about 13 kJ.

**Hypothetical radiation dose (a safety bound, not an expectation):** 1 W of textbook D–D fusion is about 8.5×10¹¹ n/s, or about 6.8×10⁶ n/cm²/s at 1 m, which is about **9 Sv/h**. Emission of this size has never been seen; reported neutron signals sit at or near background. A neutron monitor wired to a power trip still belongs in the design.

**Hydride expansion:** β-PdD expands by about 11% in volume (about 3.5% linear), so a 20 mm wire grows about 0.7 mm. Storms and a Pd-alloy patent recommend cathodes that expand ≤12% in volume.

---

## 4. Hazard register

Likelihood: **H** = expected at some point over a multi-month campaign without the mitigation; **M** = plausible; **L** = unlikely.

| # | Hazard | Cause | Consequence | Likelihood | Mitigation | Design implication (geometry) |
|---|---|---|---|---|---|---|
| 1 | D₂/O₂ deflagration or detonation, open cell | Off-gas builds up in the headspace, enclosure or room; vent blocked by condensate or a valve | Glass fragments, burns, hearing damage | M (3 known events) | Continuous N₂/Ar sweep; H₂ sensor alarm at ≤1% (NFPA 2); flame arrestor; shield | Headspace **≤20 mL**. Sweep **≥0.8 L/min per A** (≤1% D₂), ideally 2 L/min per A (≤0.4%). Vent bore ≥6 mm, no valves, falls toward the cell so condensate drains back. |
| 2 | Recombiner failure, closed cell | Catalyst flooded, wetted or poisoned (Cl⁻, S, Si, organics); undersized catalyst | Stoichiometric mixture builds, then ignites on a hot spot or when the catalyst dries out and reactivates | M–H | Hydrophobic Pt/Pd catalyst (PTFE-bound); pressure-trend interlock; thermocouple on the catalyst bed | Recombiner at the **top of the headspace, ≥20 mm above maximum liquid level, behind a splash baffle**. Capacity ≥2× the stoichiometric gas rate at I_max. Trip at **ΔP ≥ 0.1·P_fill**. |
| 3 | Recombiner hot-spot ignition | A burst of accumulated gas drives the catalyst above about 560–585 °C | Ignition inside the vessel | M | Limit catalyst mass; metal-mesh heat spreader; sintered-metal flame arrestor around the bed; keep the bed below 180 °C (hydrophobic coatings decompose above that) | Thermal path from the catalyst to the cell wall. Arrestor separating the catalyst from the bulk headspace. |
| 4 | Organic residue in O₂-enriched gas (the SRI lesson) | Machining oil, silicone grease, o-ring lubricant, fingerprints | Explosive oxidation; also contamination of the cathode surface | M | Oxygen-clean to ASTM G93; solvent plus ultrasonic clean; vacuum bake; lint-free gloves | Wetted and headspace materials limited to **PTFE, PFA, FEP, PCTFE (Kel-F), quartz, Pt, Pd, 316L**. No elastomers in the headspace; use metal or PTFE seals. |
| 5 | Stored-energy release from loaded Pd | Large cathode; hollow cathode; sudden exposure of loaded Pd to air or O₂ | Meltdown or explosion (F&P 1985, Biberian 2004) | L–M | Deload by anodic stripping or slow outgassing under inert gas before opening; no unattended operation without interlocks | Cathode volume **≤0.3 cm³** (≤4 kJ). **No sealed voids.** Supports must allow 3.5% linear growth. |
| 6 | Pressure-vessel rupture, closed cell | Over-pressure from gas generation, heating or ignition | Shrapnel | L–M | Relief valve plus burst disk vented to the hood; hydrotest at 1.5× MAWP; burst ≥4× MAWP | MAWP ≥10× P_fill (isochoric combustion) when the mixture is controlled, **≥20× P_fill** if detonation is credible. Headspace ≤50 mL. Metal body (316L) or thick PTFE inside a steel shell. |
| 7 | Electrical shock or arc | DC supplies of 10–300 V, especially in plasma electrolysis; wet benches | Electrocution, burns | M | Design for SELV **≤60 V DC**; current limit; fuses; GFCI on the AC side; enclosure interlock; E-stop | Electrode gap and electrolyte conductivity chosen so V_cell ≤ 30–40 V at I_max (see §9). Plasma electrolysis only inside an interlocked enclosure. |
| 8 | Caustic electrolyte; Li metal | 0.1–1 M LiOD (pH about 13); Li + D₂O is exothermic and releases D₂ | Eye or skin burns; fire | M | Goggles plus face shield, nitrile or neoprene gloves, eyewash; add Li in ≤100 mg pieces to chilled D₂O under Ar in a hood (69 mg Li per 100 mL at 0.1 M releases about 120 mL D₂) | Fill ports sized so filling and draining can be done without tipping the cell. |
| 9 | Aqua regia (etching) | NOCl and NO₂ fumes; gas pressure in a closed container; reacts violently with organics | Inhalation injury; bottle bursts | M | Mix fresh, small volumes, in a hood; never cap; quench into water; dedicated waste stream | Cathode fixtures that can be removed for etching and remounted without touching the surface. |
| 10 | Pyrophoric Pd black, nanopowder or co-deposit | High-surface Pd loaded with H or D dries out in air | Ignites solvents, ignites itself | M | Keep wet; passivate slowly with dilute air in N₂; handle under inert gas | Co-deposition cells must be drained and flushed under inert gas. |
| 11 | High-pressure D₂ and hydrogen embrittlement (Sieverts rigs, gas loading, cell prefill) | Cylinder at 2,000+ psi; regulator failure; high-strength steel, Ti or Ni-alloy fittings | Jet fire, over-pressure, cracked fittings | M | Lecture-bottle cylinder in a ventilated cabinet; regulator with relief; flow restrictor; He leak check; 316L with VCR fittings | All downstream parts 316L and rated above the relief set pressure. |
| 12 | Glass failure | Thermal shock; pressure; fragments thrown by a gas event | Lacerations | M | Polycarbonate enclosure ≥6 mm thick; prefer PTFE/PFA cell bodies | Secondary containment around every glass part. |
| 13 | Electrolyte dry-out or boiling | 9 g/(A·day) electrolysis loss plus evaporation (D₂O boils at 101.4 °C) | Electrodes exposed, arcing, ignition | H over long runs | Level sensor; automatic top-up; 90–95 °C trip | Reserve for ≥30 days at I_max, or automatic top-up. |
| 14 | Ionising radiation (hypothetical n/γ; X-rays from >5 kV discharges) | Nuclear process (unconfirmed); high-voltage discharge | Dose | L | Neutron plus gamma monitor with alarm and trip at 10× background; bubble dosimeters; no licensed sources | Room for a moderated He-3 tube or EJ-309 within 10–30 cm, and Pb around the NaI. |
| 15 | Tritium | Background in D₂O (61–2,500 Bq/L), enriched up to about 5× by electrolysis | Negligible dose; **false-positive** risk | M (for data) | Assay each D₂O lot; vent off-gas | Sampling port; closed cell keeps the tritium inventory accounted for. |
| 16 | Unattended multi-week runs | Power cut, PC crash, sensor failure | Any of the above, undetected | H | UPS; watchdog that fails safe (power off); remote alarms | Every trip wired in hardware, not only in software. |

Minor: PdCl₂ is a skin sensitiser, and the hot 6.25 M NaOH used to etch CR-39 is caustic. Use PPE and a hood.

---

## 5. Materials and price table

Metal spot prices: **Pd $1,198/ozt (Kitco, 2026-09-28); $1,265/ozt (Umicore, 2026-09-25)**, which is $38.5–40.7/g. **Pt $1,726/ozt (2026-09-28)**, which is $55.5/g. Pd density 12.02 g/cm³; Pt 21.45 g/cm³. Small fabricated pieces usually sell at 2–5× their melt value (est.). Scrap Pd can be sold back to refiners for most of its metal value.

| Item | Spec | Suppliers | Metal content → melt value | Expected purchase price | Source / date |
|---|---|---|---|---|---|
| Pd wire 0.5 mm | 99.95–99.99% | Surepure, Goodfellow, Thermo (Alfa) | 0.024 g/cm → 10 cm ≈ $9 | $40–100 per 10 cm (est.) | Goodfellow/Surepure listings (sourced availability) |
| Pd wire 1.0 mm | 99.9% (Thermo AA10280BS, 10 cm); 99.95% | Thermo/Fisher, Goodfellow | 0.094 g/cm → 10 cm ≈ $36 | $100–250 per 10 cm (est.) | Fisher listing (sourced availability; price behind login) |
| Pd wire 2.0 mm | 99.95% (Thermo AA14761BU, 25 cm) | Thermo/Fisher | 0.378 g/cm → 25 cm ≈ $364 | $600–1,200 (est.) | Fisher listing |
| Pd foil 25 µm, 25×25 mm | 99.95% "light tested" | Sigma/Goodfellow (GF03781863) | 0.19 g ≈ $7 | $60–150 (est.) | Sigma listing |
| Pd foil 50–125 µm, 25×25 mm | 99.95%, as rolled | Sigma/Goodfellow (GF86358077, GF68759061); Thermo 011515 (0.1 mm) | 0.38–0.94 g ≈ $15–36 | $100–300 (est.) | Sigma, Thermo listings |
| Pd rod | 4 mm × 20 mm | Goodfellow, ESPI, Surepure | 3.0 g ≈ $116 | $250–500 (est.) | est. |
| Pd sponge or powder | 99.95%, −60 mesh | Thermo, Sigma, ESPI | $/g ≈ spot | 1.3–2× spot (est.) | est. |
| Pd nanopowder | <25 nm | Sigma, US Research Nanomaterials | — | $50–150/g (est.); **pyrophoric when loaded** | est. |
| Pd–Ag 77/23 foil | Hydrogen-membrane alloy | Goodfellow, Johnson Matthey | — | 1–1.5× Pd foil (est.) | est. |
| Pd–Rh, Pd–B, Pd–Ce | Research alloys (NRL Pd–B; ENEA Pd–Ce) | **Custom melt only** (Goodfellow, ESPI, Ames Lab) | — | $1,500–5,000 per melt, with lead time (est.) | est. |
| PdCl₂ (co-deposition) | 99.9% | Sigma, Thermo | 0.13 g per 25 mL of 0.03 M | $10–30 per run (est.) | est. |
| Pt wire anode | 0.5 mm × 1 m, 99.95% | Thermo (AA10285, 1.0 mm), Goodfellow | 4.2 g ≈ $234 | $450–900 (est.) | Fisher listing |
| Pt gauze / mesh | 52 mesh, 25×50 mm | Thermo, Goodfellow | — | $300–700 (est.) | est. |
| **D₂O 99.9 atom % D** | Low-tritium grade preferred | Sigma 151882, Cambridge Isotope, United Nuclear, Heavy Water Board (India) | — | Bulk ex-factory global average **$646/kg (2024)**; research grade **$300–500/L (2025)**; retail 100 g about $1–3/g (est.); United Nuclear lists small lots at $29–39 | IndexBox; DataM Intelligence; unitednuclear.com |
| LiOD | 7.5 wt% in D₂O, ≥98 atom % D (Sigma 347450), **or** Li metal dissolved in D₂O | Sigma, SCBT | — | $150–400 per 25–50 g solution (est.); Li metal $2–5/g (est.) | Sigma listing |
| Au foil (co-deposition substrate) | 25–50 µm | Goodfellow, Sigma | — | $100–250 per 25×25 mm (est.) | est. |
| Ni mesh; ZrO₂, CaO powders; constantan (Cu55Ni44Mn1) wire 0.1–0.2 mm | Minor or alternative materials | McMaster, Goodfellow, Sigma, Omega | — | $30–100 each (est.) | est. |
| PTFE/PFA cell body and parts | Machined | Local shop | — | $100–600 (est.) | est. |
| Recombiner catalyst | 0.5% Pt or Pd on alumina, hydrophobised | Sigma, Alfa | — | $50–200 (est.) | est. |
| Burst disk, relief valve, 316L VCR fittings | Rated ≥ MAWP | Swagelok, Fike | — | $500–2,000 per closed cell (est.) | est. |
| D₂ gas | 99.8%, lecture bottle | Airgas, Linde | — | $300–700 (est.) | est. |

Avoid LiOH monohydrate as a LiOD substitute because it brings H into the electrolyte. Anhydrous LiOH adds about 0.1 at% H at 0.1 M.

---

## 6. Detector and instrumentation price table

| Item | Role | Price | Source / date |
|---|---|---|---|
| RadiaCode 103 (CsI(Tl), 8.4% FWHM) | Hobby gamma spectrometer and dose logger | **$319** | radiacode.com (sourced, 2026) |
| 2"×2" NaI(Tl) with digital MCA (Ortec digiBASE) | Gamma spectroscopy | **About $6,000 plus $2,000 for Maestro software; $9–10k complete** | Maximus Energy (2022) |
| 2"×2" NaI plus low-cost MCA (Spectrum Techniques UCS-30, used Bicron) | Gamma spectroscopy | $2,000–5,000 (est.) | est. |
| He-3 proportional tube | Thermal neutron counting in a moderator | Used $200–1,200 (e.g., SNM-16 $199; NEUTRON-LITE kit **$1,195**). New 4 atm tube $3–8k (est.). The He-3 gas shortage pushed prices from $40–85/L before 2009 to over $2,000/L | LabX, eBay, Chemistry World, GAO-11-753 |
| Ludlum 42-41L PRESCILA | Proton-recoil fast/thermal neutron dose probe | **$2,880** (2017 list) | Ludlum price list 2017 |
| Ludlum 12-4 rem ball | Neutron dose-equivalent survey meter | About $2,000+ (older forum figure); likely $4–6k new (est.) | fusor.net |
| BTI BD-PND bubble detectors | Personal neutron dosimeter; gamma-blind | About **$300 each** (2015 forum); likely $350–500 now (est.) | bubbletech.ca, lenr-forum |
| EJ-309 liquid scintillator, 2"×2" with PMT | n/γ pulse-shape discrimination, fast neutrons | $3–6k (est.); digitizer (e.g., CAEN desktop) $6–12k (est.) | Eljen (high flash point, 144 °C) |
| CR-39 (TASL Tastrak; Fukuvi) | Charged-particle track detector | $3–15 per chip; $100–300 per sheet (est.) | tasl.co.uk |
| CR-39 readout | Microscope (manual) or TASLImage (automated) | $300–2,000 (manual, est.); automated readers are far dearer | est. |
| H₂ detector (catalytic or thermal-conductivity, ≤1% alarm) | NFPA 2 compliance | $200–1,500 (est.) | est. |
| Gamry Reference 3000 | Potentiostat/galvanostat with EIS | **$17,995** (2015 list) | Scribd price list |
| Gamry Interface 1010E; BioLogic SP-200 | Potentiostat | $10–30k (est.) | est. |
| Keithley 2450/2460 SourceMeter | Precision constant current with 4-wire sense | $6–10k (est.) | est. |
| Bench PSU (Rigol DP832, Siglent SPD3303X) | Hobby constant current | $300–600 (est.) | est. |
| Keysight DAQ970A plus multiplexer cards | Precision DAQ (RTDs, V, I) | $3–5k (est.) | est. |
| Pt100 Class A 4-wire RTDs / calibrated thermistors | Calorimetry temperatures | $20–100 each (est.) | est. |
| TEC modules, 40×40 mm, for a Storms-style Seebeck calorimeter | Heat-flux sensing | $3–15 each; 20–60 needed (est.) | Storms, "How to make a cheap and effective Seebeck calorimeter" |
| Recirculating chiller (±0.02 °C) | Calorimeter heat sink | $3–8k (est.) | est. |
| Vacuum tube furnace, 1200 °C, with rotary pump | Pd annealing | $4–10k (est.) | est. |
| Glovebox / glove bag (Ar) | D₂O and Li handling | $100 (bag) to $40–60k (box) (est.) | est. |

**Outsourced services (est.):**

| Service | Price |
|---|---|
| SEM/EDS | $100–400/h |
| EBSD grain and texture maps | $200–500 per sample |
| AFM | $100–200/h |
| XRD texture | $100–300 per sample |
| ICP-MS impurity analysis | $50–200 per sample |
| GDMS of bulk Pd | $500–1,000 per sample |
| Vacuum heat-treat | $100–300 per batch |
| Pd sputtered films | $500–2,000 per run |
| Tritium by liquid scintillation counting | $50–300 per sample |
| **⁴He by high-resolution mass spectrometry** (must resolve D₂ at 4.0282 u from ⁴He at 4.0026 u; few labs offer it) | $500–2,000 per sample |

---

## 7. Budget tiers

### (a) About $5k: hobbyist or garage

| Item | $ |
|---|---|
| Pd: 2× 1 mm × 5–10 cm wire plus 1 foil | 500 |
| Pt anode wire | 500 |
| D₂O, 250–500 g | 500 |
| LiOD solution or Li metal; PdCl₂, LiCl, Au substrate (co-deposition) | 400 |
| PTFE cell bodies, fittings, vent, bubbler | 400 |
| Bench PSU with 4-wire resistance measurement (for D/Pd) | 500 |
| RTDs plus 24-bit ADC logger; insulated isoperibolic jacket | 500 |
| CR-39 chips, NaOH etch setup, microscope | 600 |
| RadiaCode 103 plus 2 BD-PND bubble detectors | 1,000 |
| H₂ sensor, polycarbonate enclosure, PPE, eyewash | 600 |
| **Total** | **about 5,500** |

**Can do:** Galileo co-deposition with CR-39, a loading demonstration by resistance ratio, and isoperibolic calorimetry at about ±50–150 mW (2–5%). **Cannot do:** a credible heat claim, neutron counting above background, a safe closed cell, or cathode annealing. Open, swept, vented cells only, never left unattended.

### (b) About $50k: small lab (recommended)

| Item | $ |
|---|---|
| Pd from 2–3 vetted lots (99.95–99.99%), wires and foils; one Pd–Ag or alloy sample | 4,000 |
| D₂O, 2 kg (low-tritium lot, pre-assayed) plus H₂O controls | 2,000 |
| Pt anodes and mesh | 1,500 |
| Two closed PTFE-lined 316L cells: recombiner, burst disk, relief valve, pressure transducer, VCR fittings | 5,000 |
| Storms-style Seebeck calorimeter, ×2 (active and H₂O control): TECs, Al box, insulation | 3,000 |
| Recirculating chiller | 5,000 |
| Keithley 2460 or Gamry 1010E (constant current plus EIS) | 10,000 |
| Keysight DAQ970A with RTDs, pressure logging, and hardware interlock relay board | 5,000 |
| Vacuum tube furnace and pump | 6,000 |
| Used He-3 tube in HDPE moderator plus counting electronics | 2,000 |
| 2"×2" NaI with MCA | 3,000 |
| CR-39 program plus bubble detectors | 1,000 |
| Outsourced SEM/EBSD/ICP-MS | 2,500 |
| Tritium LSC on D₂O lots and runs (about 10 samples) | 1,000 |
| Safety: H₂ detection, enclosure, UPS, watchdog, gas cabinet | 2,000 |
| **Total** | **about 53,000** |

**Can do:** Seebeck calorimetry at about ±20–60 mW (0.2–0.7%, per Storms) with paired D₂O and H₂O cells. Also in-house annealing and etching, loading tracked by resistance plus EIS, closed cells with the ΔP interlock, neutron and gamma trips, and tritium assays. **Missing:** ⁴He measurement (outsourcing adds $5–15k), parallel statistics, and staff.

### (c) About $500k: professional

| Item | $ |
|---|---|
| 1.5 FTE for 2 years (electrochemist plus technician) | 250,000 |
| 6–8 parallel cells with dual calorimetry (Seebeck plus mass-flow), multichannel potentiostat (BioLogic VMP-3e class) | 70,000 |
| Pd program: custom melts (Pd–B, Pd–Rh, Pd–Ce), 5 lots, sputtered films | 25,000 |
| ⁴He: high-resolution QMS or sector-field MS with getter purification, **or** outsourced contract | 60,000 |
| Neutrons: EJ-309 array (4×) plus digitizers; He-3 long counter | 40,000 |
| Gammas: HPGe (used or entry-level) | 30,000 |
| Glovebox, tube furnaces, electropolishing station | 25,000 |
| Outsourced characterisation (EBSD, GDMS, TEM), tritium LSC | 15,000 |
| Safety engineering: gas cabinet, ventilation to NFPA 2, pressure-vessel review | 10,000 |
| Contingency | about 30,000 |

**What it can do:** statistically powered runs (n ≥ 20 cathodes with controls), heat measured against ⁴He, blind analysis, and external review. Most of the spending is staff. The instruments are only about a third of the total.

---

## 8. Cathode preparation recipes

### 8.1 ENEA (Violante), as used by Energetics/SKINR and Letts

Reported excess-heat reproducibility above 60%. Energetics runs using Violante foils showed excess heat in about 73% of runs.

1. **Material:** high-purity Pd, 99.95–99.99%, from a *vetted lot*. Pd varies greatly from batch to batch, and the patent notes there is no standard protocol.
2. **Cold roll to foil**, rotating the sample **120° about the surface normal between passes**. The target is about **50 µm** thick. Intermediate anneals as needed.
3. **Ultrasonic cleaning** in solvent and then DI water.
4. **Vacuum anneal:** ribbons at **450 °C for 30 min, then 850 °C for 90 min** in vacuum. The final 850 °C anneal enlarges grains and relieves stress.
5. **Target microstructure:** surface grains mostly **15–40 µm, ideally about 35 µm** (acceptable range 5–100 µm), with strong **<100> texture**. Verify by EBSD or XRD.
6. **Etch before every run:** **50% aqua regia for 2 min** at room temperature, or warmer if the oxide resists (maximum about 100 °C). Etching roughens the grains, deepens grain boundaries, and raises double-layer capacitance and effective surface area, which gives faster and higher loading.
7. **Characterise:** SEM/AFM for surface morphology, XPS for surface contamination.

### 8.2 Letts–Cravens (ASTI 2004; patents US 10,559,831 and 11,563,217)

1. Cold-work to about **50% thickness reduction** (for example 0.5 mm → 0.25 mm) to create dislocations.
2. Polish with a rotary brush and Al₂O₃ abrasive.
3. Etch in aqua regia for about 2 min at up to 100 °C.
4. Anneal at **800–900 °C for ≥30 min** (typically 850 °C), adjusting per lot to reach about 35 µm grains.
5. Use small cathodes (about 0.15 g) and load to roughly **10⁷ C per mole of Pd** before expecting heat (Cravens & Letts, "Enabling Criteria", a review of 167 papers from 1989–2007).
6. Prefer alloys and treatments that give **≤12% volume expansion** on loading.

### 8.3 SRI (McKubre)

1. Twice vacuum-melted Pd, machined to a wire or rod.
2. **Vacuum anneal at 800 °C for 3 h**, or 850 °C for 2.5 h, then **backfill with D₂ at temperature**.
3. Run criteria: **D/Pd ≥ 0.875–0.9** held for an incubation period. Current density above threshold: excess power scales with *i* above about **100 mA/cm²**. The threshold is clearer and higher with a wire cathode and concentric anode than with parallel plates.
4. Measure D/Pd in situ by 4-wire resistance ratio R/R₀, which requires a wire at least about 2 cm long.

### 8.4 Fleischmann–Pons (baseline geometry)

- Cathode: Pd rod, **2 mm diameter × 12.5 mm**, spot-welded to a Pt lead.
- Anode: Pt wire, concentric.
- Electrolyte: **0.1 M LiOD** in D₂O.
- Cell: Pyrex Dewar, silvered in the upper part; electrodes held by a Kel-F plug.
- Operation: constant current, stepped from **10 up to 1,000 mA/cm²**, with D₂O topped up.

### 8.5 Storms' guidelines ("How to produce the Pons–Fleischmann effect")

- Reject cathodes that crack or expand grossly on a trial load–deload cycle.
- Load near room temperature at moderate current density, then raise the temperature step by step toward boiling. Limit high-current pre-electrolysis "activation" to a couple of cycles.
- Surface deposits (Li, Pt from the anode, Si from glass) shape the outcome. Control them.

### 8.6 SPAWAR Pd/D co-deposition (Szpak/Mosier-Boss; Galileo protocol)

1. Electrolyte: **0.03 M PdCl₂ + 0.3 M LiCl in D₂O**. Substrate: Au foil or wire (Ag, Ni and Pt were also used). Anode: Pt.
2. Galvanostatic steps: **1.0 mA/cm² for 8 h → 3 mA/cm² for 8 h → 5.0 mA/cm² until all Pd²⁺ is reduced** (the solution turns colourless). Then **30–50 mA/cm² for 2–3 h** to keep gas visibly evolving, and afterwards step up the current. An external magnetic or electric field is optional.
3. CR-39 goes against the cathode. Standard etch is 6.25 M NaOH at 70 °C for about 6 h. Run H₂O and blank (no Pd) controls to separate tracks from chemical or mechanical pitting (see "Interpreting CR-39 Detectors used in Pd/D Co-deposition", JCMNS).
4. **Safety:** the co-deposit is pyrophoric when dry, and one catastrophic thermal event was reported.

### 8.7 Other programs

- **Google/UBC/MIT:** Benck et al. (Chem. Mater. 2019) reached **H/Pd near 1** by electrochemical insertion. Composition is a dynamic insertion/evolution balance, so it has to be measured operando. The Nature 2019 perspective found no excess heat. The 2025 UBC follow-up found that electrochemical loading **raised plasma-driven D–D fusion rates by about 15%**, but that route requires a registered radiation-producing machine (§9).
- **MFMP:** open, live replications of Celani's constantan wires reported 12.5% and then 5.3% apparent excess (quantumheat.org). Useful as a model for open data, not as confirmation of an effect.

### Common anneal and etch parameters (synthesis)

| Parameter | Value |
|---|---|
| Atmosphere | ≤10⁻⁵ mbar vacuum or flowing Ar/H₂ (use D₂ backfill if it is available) |
| Temperature | **850 °C** (range 800–900) |
| Time | **1.5–3 h** |
| Cooling | Furnace cool |
| Handling | Fluoropolymer or quartz boats only (no graphite, no Ni); gloved |
| Etch | 50% aqua regia, 2 min, just before mounting; rinse in DI water, then D₂O |

---

## 9. Regulatory notes (US focus)

- **D₂O:** no NRC license is needed to buy or possess it domestically. Large acquisitions may be reported by vendors. Institutional vendors (Sigma, Fisher, Cambridge Isotope) generally require a verified institutional account. **Export** is controlled under 10 CFR 110: a general license covers ≤10 kg deuterium (about 50 kg D₂O) per shipment and ≤200 kg per year per country to non-embargoed destinations.
- **D₂ gas:** shipped as a DOT Class 2.1 flammable gas (UN1957). Storage and use fall under NFPA 55, NFPA 2 and OSHA 29 CFR 1910.103.
- **Tritium:** the exempt quantity for H-3 is **1,000 µCi (37 MBq)** in 10 CFR 30.71 Schedule B (about 2×10¹⁶ atoms). Claimed LENR tritium yields (10¹¹–10¹⁵ atoms) fall well below it. Commercial D₂O already carries **61–2,500 Bq/L** of tritium, rising with purity, and electrolysis enriches it up to about 5×. **Assay every lot.**
- **Radiation sources:** use only exempt check sources, or borrow calibration sources at a licensed facility. **Avoid AmBe, Cf-252 and other licensed neutron sources.**
- **Radiation-producing machines:** anything that accelerates electrons or ions to >5–10 kV (glow discharge, fusor, ion beam) can produce X-rays or neutrons. Most states require it to be registered with the state radiation control program. That keeps accelerator-based D–D measurements out of the low tiers.
- **Codes and standards:** NFPA 2 (H₂ detection at ≤1% by volume; ventilation ≥1 scf/min/ft² of floor area where H₂ is stored or used); NFPA 45 (labs); NFPA 55; NFPA 70/70E (electrical); OSHA 1910.1450 (chemical hygiene plan); ASME BPVC VIII (vessels over 15 psig; very small-diameter vessels are exempt, but follow its design margins anyway); ASTM G93 (oxygen cleaning).
- **Waste:** recover Pd through a refiner. Neutralise LiOD. Aqua regia is hazardous waste (corrosive and oxidiser). Tritiated water below exempt levels needs no special handling, but document it.

---

## 10. Design constraints the geometry must satisfy

1. **Headspace volume:** ≤20 mL for open cells and ≤50 mL for closed cells. This caps the worst-case stoichiometric energy at about 0.13 kJ (open) or 0.34 kJ (closed) at 1 bar.
2. **Open-cell vent path:** inert sweep ≥0.8 L/min per amp at I_max (≥2 L/min per A preferred). Vent bore ≥6 mm, with no valves or restrictions. Condensate must drain back into the cell. Include a bubbler or check valve and a flame arrestor, and exhaust to a hood or outdoors.
3. **Closed-cell pressure rating:** MAWP ≥10× the absolute fill pressure, or ≥20× if detonation cannot be excluded. Hydrotest at 1.5× MAWP. Relief valve set ≤ MAWP and a burst disk at 1.1× relief, both vented to the exhaust.
4. **Closed-cell interlock:** trip cell current at **ΔP ≥ 0.10 × P_fill** (absolute), with a response time under 60 s. Start the cell O₂-free (evacuate, then backfill with D₂).
5. **Recombiner placement:** top of the headspace, ≥20 mm above maximum liquid level, behind a splash baffle, inside a sintered-metal flame arrestor, and thermally sunk to the wall. Thermocouple-monitored, with a trip at 150 °C. Hydrophobic catalyst sized for ≥2× the stoichiometric gas rate at I_max.
6. **Cathode volume:** ≤0.3 cm³, with no enclosed voids or hollow cathodes. Mounts must allow **3.5% linear growth** (≈0.7 mm per 20 mm).
7. **Wire cathodes for loading measurement:** ≥20 mm active length, with separate current and voltage leads (4-wire) for R/R₀.
8. **Current-density uniformity:** concentric anode (cylinder or helix) around a wire cathode, with the gap uniform to ±10%. Anode area ≥3× cathode area. Parallel plates only with guard geometry.
9. **SELV:** V_cell ≤60 V DC at I_max. For 0.1 M LiOD (ρ ≈ 60 Ω·cm in D₂O; bubbles can double it), a 1 mm × 20 mm wire with a 10 mm-radius concentric anode is about 14 Ω, or about 8 V at 0.31 A (500 mA/cm²). A 1 cm² plate needs a gap of **≤5 mm** at 1 A.
10. **Wetted and headspace materials:** PTFE, PFA, FEP, PCTFE, quartz, Pt, Pd, 316L only, oxygen-cleaned. No elastomers or greases in the headspace. Avoid borosilicate in prolonged contact with hot LiOD if Si contamination is to be controlled.
11. **Electrolyte inventory:** a reserve of ≥30 days × 9 g/(A·day) for open cells, or automatic top-up. Level sensor interlocked to the current.
12. **Thermal limits:** electrolyte ≤95 °C (D₂O boils at 101.4 °C), with a hardware thermal cutoff independent of the DAQ.
13. **Secondary containment:** polycarbonate enclosure ≥6 mm thick around every glass part and around closed cells. Keep ≥1 m of operator standoff during current steps and pressure changes. **No opening, tilting or lifting of any cell until it has been deloaded, purged and cooled.**
14. **Detector access:** leave room for a moderated neutron detector within 10–30 cm of the cathode, a CR-39 position adjacent to the cathode, and a lead-shielded NaI. Avoid large metal masses between cathode and detectors. Neutron or gamma alarm at 10× background trips the power.
15. **Loading gas systems** (if gas-loaded or prefilled): 316L with metal-gasket fittings, a regulator with relief, a flow restrictor, and a lecture-bottle-scale cylinder in a ventilated cabinet. Ceiling-level H₂ sensor with a ≤1% alarm.
16. **Fail-safe control:** every trip (pressure, temperature, level, H₂, radiation, E-stop, watchdog) removes cell power in hardware. UPS on the monitoring system.
17. **Calorimetric boundary:** open cells must correct for the enthalpy carried off by gas (I × 1.527 V). Closed cells keep the recombination heat inside the boundary, at the price of constraints 3–5.

---

## 11. References

- Forensic analyses of explosion debris from the 2 Jan 1992 Pd/D₂O incident at SRI (LLNL): https://www.osti.gov/biblio/212468 ; https://digital.library.unt.edu/ark:/67531/metadc665463/ ; https://inis.iaea.org/records/pjf88-kav54
- The January 2, 1992, explosion in a deuterium/palladium electrolytic system at SRI: https://inis.iaea.org/records/jw89d-fvx92
- Deseret News, "Equipment failure blamed..." (1992): https://www.deseret.com/1992/1/4/18960119/equipment-failure-blamed-in-lab-explosion-that-killed-cold-fusion-researcher-br/
- Michael McKubre (incident account): https://en.wikipedia.org/wiki/Michael_McKubre
- Ruer & Biberian, "Reanalysis of an Explosion in a LENR Experiment," JCMNS 26 (2018): https://jcmns.org/article/72472-reanalysis-of-an-explosion-in-a-lenr-experiment
- Mizuno 2005 explosion: https://sciencespot.co.uk/2005-3-10-18423-3423.html ; https://en.wikipedia.org/wiki/Tadahiko_Mizuno
- F&P 1985 meltdown: https://matheasy.substack.com/p/martin-fleischmann-recounts-the-1985 ; https://encyclopedia.pub/entry/31286
- Hydrogen safety data: https://en.wikipedia.org/wiki/Hydrogen_safety ; https://www.aiche.org/sites/default/files/docs/pages/the_elemental_-_hydrogen_flammability.pdf ; https://www.osti.gov/servlets/purl/1721461
- Payman & Titman, "Limits of Inflammability of Hydrogen and Deuterium in Oxygen and in Air," Nature 137 (1936): https://www.nature.com/articles/137190a0
- Recombiner catalyst behaviour: https://image-ppubs.uspto.gov/dirsearch-public/print/downloadPdf/4350610 ; https://glc.ans.org/nureth-16/data/papers/14071.pdf
- NFPA 2 guidance: https://www.labmanager.com/lab-gas-generator-safety-managing-hydrogen-flammability-pressure-risks-and-ventilation-requirements-35520 ; https://h2tools.org/bestpractices/laboratory-safety/laboratory-design/ventilation ; https://altfuelgarage.frontierenergy.com/wp-content/uploads/2018/05/Hydrogen-Requirements-Best-Practices-NFPA-2.pdf
- Pd price: https://www.kitco.com/charts/palladium ; https://pmm.umicore.com/en/prices/palladium/
- Pt price: https://tradingeconomics.com/commodity/platinum
- Pd/Pt catalog listings: https://www.fishersci.com/shop/products/palladium-wire-1-0mm-0-04in-dia-99-9-metals-basis-thermo-scientific/AA10280BS ; https://www.fishersci.com/shop/products/palladium-wire-2-0mm-0-08-in-dia-99-95-metals-basis-thermo-scientific-1/AA14761BU ; https://www.sigmaaldrich.com/US/en/product/aldrich/gf68759061 ; https://www.thermofisher.com/order/catalog/product/011515.FF ; https://www.goodfellow.com/usa/palladium-spooled-wire-group ; https://www.surepure.com/Palladium-Wire-Rod/a/8,1
- D₂O pricing and market: https://www.indexbox.io/search/price-for-heavy-water-deuterium-oxide-the-united-states/ ; https://www.datamintelligence.com/research-report/heavy-water-market ; https://unitednuclear.com/chemicals-metals-c-69/deuterium-oxide-p-135.html ; https://www.sigmaaldrich.com/US/en/product/aldrich/151882
- LiOD: https://www.sigmaaldrich.com/catalog/product/aldrich/347450
- 10 CFR 110 export: https://www.ecfr.gov/current/title-10/chapter-I/part-110 ; https://biennialsandeducation.org/can-you-buy-heavy-water
- 10 CFR 30 exemptions: https://www.ecfr.gov/current/title-10/chapter-I/part-30 ; https://www.morganlewis.com/blogs/upandatom/2026/06/material-changes-nrc-proposes-overhaul-of-byproduct-materials-regulations
- Tritium in commercial D₂O: https://link.springer.com/article/10.1007/s44211-024-00615-6 ; https://files.ncas.org/erab/apx3b.htm
- He-3 shortage: https://www.chemistryworld.com/news/shortages-spur-race-for-helium-3-alternatives-/3003620.article ; https://www.gao.gov/assets/a585515.html ; https://www.labx.com/item/neutron-lite-neutron-detector-spectrometer-mca-he3-helium-3/scp-221792-f5fbc219-815d-4f6a-aed7-89f9568ee49e
- Detectors: https://radiacode.com/products/radiacode-103?lang=en ; https://maximus.energy/index.php/2022/07/02/ortec-digibase-e-gamma-spectrometer/ ; https://device.report/m/0f634454662db1c2ad91fcaf781fd0774eb9940cb1b3e566877286b340879f87.pdf ; https://bubbletech.ca/product/bd-pnd-personal-neutron-dosimeter/ ; https://www.lenr-forum.com/forum/thread/2230-bd-pnd-neutron-detectors/ ; https://eljentechnology.com/products/liquid-scintillators/ej-301-ej-309 ; https://www.tasl.co.uk/tastrak-padc.php
- Gamry pricing (2015): https://www.scribd.com/document/309879595/Ceni-IntlSalesPriceList-August2015
- Seebeck calorimetry (Storms): https://lenr-canr.org/acrobat/StormsEhowtomakea.pdf ; https://lenr-canr.org/acrobat/StormsEdescriptioa.pdf ; https://www.osti.gov/etdeweb/biblio/21066223
- Storms, "How to Produce the Pons–Fleischmann Effect": https://www.lenr-canr.org/acrobat/StormsEhowtoprodu.pdf
- Letts & Cravens, cathode fabrication: https://www.lenr-canr.org/acrobat/LettsDcathodefab.pdf ; https://lenr-canr.org/acrobat/LettsDlaserstimu.pdf
- Cravens & Letts, "Enabling Criteria": https://www.lenr-canr.org/acrobat/CravensDtheenablin.pdf ; https://www.lenr-canr.org/acrobat/CravensDfactorsaff.pdf
- Exothermically responsive cathodes patents: https://image-ppubs.uspto.gov/dirsearch-public/print/downloadPdf/10559831 ; https://image-ppubs.uspto.gov/dirsearch-public/print/downloadPdf/11563217
- ENEA/SKINR: https://www.researchgate.net/publication/283861408_Sidney_Kimmel_Institute_for_Nuclear_Renaissance ; https://mospace.umsystem.edu/xmlui/handle/10355/37370 ; https://www.researchgate.net/publication/237284370_Material_Science_on_Pd-D_System_to_Study_the_Occurrence_of_Excess_Power ; https://jcmns.org/article/72458.pdf
- McKubre calorimetry and loading: https://lenr-canr.org/acrobat/McKubreMCHcalorimetr.pdf ; https://lenr-canr.org/acrobat/KunimatsuKdeuteriuml.pdf
- F&P calorimetry and cell: https://lenr-canr.org/acrobat/Fleischmancalorimetr.pdf ; https://www.lenr-canr.org/acrobat/LonchamptGreproducti.pdf
- Co-deposition: https://www.lenr-canr.org/acrobat/SzpakScalorimetra.pdf ; https://www.lenr-canr.org/acrobat/MosierBosscharacteri.pdf ; https://jcmns.org/article/72567.pdf ; https://www.researchgate.net/publication/283569283_Condensed_Matter_Nuclear_Science_Using_PdD_Co-Deposition
- Google/UBC/MIT: https://www.nature.com/articles/s41586-019-1256-6 ; https://pubs.acs.org/doi/abs/10.1021/acs.chemmater.9b01243 ; https://phys.org/news/2025-08-room-temperature-reactor-electrochemistry-boost.html
- MFMP: http://www.quantumheat.org/ ; https://www.researchgate.net/publication/286466066_Martin_Fleischmann_Memorial_Project_status_review
- 316L hydrogen embrittlement: https://www.sciencedirect.com/science/article/abs/pii/S0921509399003196

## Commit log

2026-09-29 M5: stopping-power/range engine validated against NIST PSTAR/ASTAR
    Claude-Session: https://claude.ai/code/session_017hjnY9m5YDcsx8N2cwZHmR
2026-09-29 M4: axisymmetric FV thermal model of closed cell in ISO/flow/Seebeck calorimeters
2026-09-29 M2: loading model, FV current-distribution solver, geometry scenarios
2026-09-29 M4: power-measurement, chemistry/He, noise, gas-phase, DFM and budget models
2026-09-29 M2: electrochemistry write-up with summary for lead; g=4 mm C3 case in cell budget
2026-09-29 M7: E0 IPC kinematics, vectorised e+-/gamma MC, reference geometry, Q1 transport results
2026-09-29 M3: DFM permeation model (steady chart, exit finishes, transients) and mechanics (FvK plate, grid, films, cracking)
2026-09-29 M6: gratings (RCWA), field enhancement, phonon/mechanical modes, skins, sector flux and collimation, PSD targets
    Claude-Session: https://claude.ai/code/session_0136Z4mzScYPuirEzgLQU1UJ
    [m6_grating_optima.csv]
2026-09-29 ADR-002 revision 2: regimes, thin membrane, pressure-balanced front, electrical hygiene, array
    Claude-Session: https://claude.ai/code/session_01UhtcJJuepH5roxPVCdThz4
2026-09-29 M7: detector-efficiency scan, background/MDA model, modulation protocol study, calibration plan, verification suite
2026-09-29 RT-1C: statistics script (trials factor, DFM T1 reach, sample count, Bayes posterior)
    Claude-Session: https://claude.ai/code/session_018TQztKmjHmh8LeSmh6Dp4M
2026-09-29 RT-1C: statistics, inference and credibility review of iteration-1
    Ranked findings (3 critical, 8 major), frozen pre-registration skeleton
    with gatekeeping, blinding/salting scheme, sensitivity and sample-count
    recomputation.
    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
2026-09-29 M7: write-up (gamma/e+e- channel, detector layout, backgrounds/MDA, modulation protocol, calibration) + final outputs
2026-09-29 Iteration-1 rev B: single-regime membranes, 12 um, all-metal He-tight cell, DFM-8 in two stages, C3-G and C1 promoted to Tier 1
    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
2026-09-29 3D CAD model of rev B (CadQuery): DFM cell and 8-cell house as STEP/STL/glTF, plus interactive viewer
    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
    [dfm_cell.step, dfm_cell.stl, dfm_house.step]
2026-09-29 ADR-006: gamma station (NaI well, separate Pb stand) and 1-6 h current-steered lock-in from M7; T2 frozen into primary family
    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
2026-09-29 ADR-007 / iteration-1 rev C: D2 recycle loop and two-sided trips, pressure hierarchy, 0.30 mm grid, press bond with Pd-only gauge rim, jackets, Si protection, re-baselined budget and schedule (red-te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
2026-09-29 3D model and drawings to rev C: 0.30 mm grid, two-fold Pt annulus with Pd-only gauge rim, aux cathode, jacket, D2 recycle loop, relief valve; gamma station model; house LaBr3 removed
    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
    [dfm_cell.step, dfm_cell.stl, dfm_house.step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]
